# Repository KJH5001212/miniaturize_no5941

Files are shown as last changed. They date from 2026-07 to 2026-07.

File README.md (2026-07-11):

# Discrete Potentiostat (초소형 무선충전 크로노암페로메트리)

AD5941 없이 디스크리트 듀얼 앰프로 구성한 3전극 크로노암페로메트리 디바이스.
WE-RE 간 **+0.5 V 고정 바이어스**, nA~µA 전류 측정, BLE 스트리밍, Qi 무선충전.

## 확정 부품

| 블록 | 부품 | 역할 |
|---|---|---|
| AFE | **LPV802** (듀얼, 나노파워) | A: 컨트롤 앰프 (CE 구동, RE 센스) / B: TIA (WE 전류→전압) — 0.32 µA/ch, Ib 0.1 pA |
| 레퍼런스 | **REF35102QDBVR** (1.024 V) | WE 가상전위 + 바이어스 분압 원천 |
| MCU/BLE/ADC | **nRF52832-QFAA (칩다운)** | 내장 SAADC(차동, 12-bit+오버샘플링)로 측정, BLE 전송. 32 MHz 수정 + Johanson 매칭필터 + 칩안테나 |
| LDO | **MIC5205-3.3** | 3.3 V 단일 레일 |
| 무선충전 | **BQ51013BRHLR** | Qi 수신, 레귤레이티드 5 V 출력 (VQFN-20) |
| 충전기 | **MCP73832T-2ACI/OT** | 리튬 충전 20 mA (=1000/RPROG), 종지 ~1.5 mA, SOT-23-5 |
| 배터리 | **LIR2032** | 3.7 V / ~40 mAh 코인셀 |

## 신호 체인

```
Qi 코일 ─ BQ51013B(5V) ─ MCP73832(20mA) ─ LIR2032 ─ MIC5205 ─ 3.3V ─┬─ nRF52832
                                                                     └─(GPIO 스위치드)─ REF35102, LPV802

REF35102 1.024V ──────────────────────────── TIA(+in): WE 가상전위 = 1.024V
      └─ 분압(1.00M/1.00M, 1:1) → 0.512V ── 컨트롤앰프(+in): RE 목표

E_cell = WE − RE = 1.024 − 0.512 = +0.512 V (대략 0.5 V 고정, 요구사항 충족)

WE → LPV802-B (TIA, RF=1MΩ) → V_out = 1.024 + I×RF
V_out, 1.024V → nRF52832 SAADC 차동 입력 → I = ΔV / RF → BLE
```

## 폴더 구성

- `hardware/design.md` — 회로 상세 설계 + 계산 (바이어스, TIA, SAADC, 충전, 전원, 보호)
- `hardware/bom.md` — 전체 BOM (수동소자 포함)
- `hardware/kicad/` — 회로도 + 23.4×22 mm 6층 PCB (배선 완료) + 생성기 스크립트
- `firmware/` — **펌웨어 (SAADC 직접측정, 구현 완료)** — 프로토콜/파라미터는 `firmware/README.md`
- `firmware-plan.md` — 포팅 계획 원문 (구현 완료 — 이력 참고용)

## 기존 ad5941 프로젝트와의 관계

BLE 프로토콜(NUS + JSON), 무손실 버퍼링, 런 모드(연속/타이머/사이클), Android 앱은
**그대로 재사용**한다. 교체되는 것은 측정 엔진뿐: SPI+AD5941 → SAADC+디스크리트 AFE.

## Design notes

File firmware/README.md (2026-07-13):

# 디스크리트 포텐쇼스탯 펌웨어 (nRF52832 SAADC 직접측정)

WE-RE **+0.512 V 하드웨어 고정 바이어스**(REF35102 + 1:1 분압)를 걸고,
LPV802 TIA 출력을 **nRF52832 SAADC 가 직접 측정**하는 크로노암페로메트리 펌웨어.
AD5941 버전(`/firmware`)과 **BLE 프로토콜 동일** — 기존 안드로이드 앱이 무수정으로 동작하고,
측정 파라미터(rf/os/게인 등)를 앱에서 조절하는 확장 필드가 추가됐다.

## AD5941 버전과의 차이

| | AD5941 버전 (`/firmware`) | 이 펌웨어 |
|---|---|---|
| 측정 | AD5941 이 측정, nRF 는 SPI 수신 | **nRF SAADC 가 직접 측정** (SPI 없음) |
| 전위 | LPDAC 로 생성 (+0.5 V) | 하드웨어 고정 (+0.512 V, REF35102) |
| 레인지 | RTIA 저항 전환 (11단) | **SAADC 게인 전환 (3단)** — RF 는 고정 저항 |
| RF | 내부 RTIA | 외부 2 MΩ (R9 — 교체 가능) → **`rf` 런타임 설정, 기본값 2M** |
| 분해능 | RTIA 오토레인지 | HW 오버샘플링(`os`) + 게인 4 구간, ≤0.1 nA |
| 캘리브레이션 | 없음 | **zero(오프셋)/cal(스케일)** — NVM 저장 |
| 배터리 | 없음 | VBAT 감시, 3.3 V 경고 / 3.0 V System OFF |

## 구성

| 파일 | 역할 |
|---|---|
| `src/main.c` | 측정 스레드(페이싱·오토레인지·캘리브레이션) · BLE NUS · 배터리 정책 |
| `src/meas.c` | SAADC 엔진 (차동 AIN0−AIN1, 게인 3단, HW 오버샘플) + AFE 전원 + VBAT/충전/Qi |
| `src/store.c` | `rf`/`os`/캘리브레이션 NVM 영속화 (settings/NVS) |
| `src/databuf.c` | 무손실 링버퍼 + ACK 윈도우 (AD5941 버전 그대로) |
| `src/flog.c` | **플래시 오프라인 백로그** — 폰 없이 측정, 재연결 시 자동 동기화 (96KB, ~6,100샘플) |
| `src/cmd.c` | JSON 명령 파서 (rf/os/zero/cal 확장) |
| `app.overlay` | 보드 핀맵 · SAADC 활성 · LDO 모드(DCC 미접속 보드 기준) |
| `prj.conf` | BLE(NUS)/ADC/FPU/RTT/settings/LFRC 설정 |

## 측정 원리

- **바이어스**: 하드웨어 고정. AVDD 급전 GPIO(P0.26) HIGH → REF35102(1.024 V) + LPV802 급전(~2 µA),
  50 ms 안정화 후 샘플링. 정지 시 LOW → 소모 0 + CE 차단(전극 분극 방지).
  (회로도 요건: DVDD→AVDD 상시 연결(R7 등) 제거, AVDD 는 P0.26 이 단독 급전)
- **TIA**: `V_TIA = 1.024 V + I×RF`. SAADC **차동**(AIN0=TIA_OUT, AIN1=1.024 V)이라
  ΔV = I×RF 를 오프셋 없이 직접 획득.
- **게인 레인지** (RF=1 MΩ 기준): idx0 = gain4 (±150 nA, LSB 73 pA) /
  idx1 = gain1 (±0.6 µA) / idx2 = gain1/2 (−0.9~+2.1 µA).
  오토레인지: |ΔV| > 85 % FS → 게인 다운, < 18 % FS → 게인 업 (히스테리시스+settle 폐기).
- **분해능**: HW 오버샘플 `os`(기본 64×) + 출력주기 내 소프트 평균 → ≤0.1 nA (요구 1 nA 대비 10×).
- **전류 환산**: `I[nA] = (ΔV/rf_ohm)×1e9 × scale − off[gain]` — scale/off 는 캘리브레이션값(NVM).

## BLE 프로토콜 (NUS, JSON 라인)

### 명령 (앱 → 기기) — 기존 앱 호환

```json
{"cmd":"start","mode":"continuous|timed|cycle","rate":10,"dur":60,"on":5,"off":295,"cycles":0,"auto":1,"range":0}
{"cmd":"config", ...같은 필드... }        // 실행 없이 설정만
{"cmd":"stop"}  {"cmd":"status"}  {"cmd":"ack","seq":1234}
```

### 확장: 측정 파라미터 (config/start 에 추가 필드)

| 필드 | 의미 | 범위 | 비고 |
|---|---|---|---|
| `rf` | TIA RF [Ω] | 10 k~100 M | 보드에서 RF 교체 시 전송 → **NVM 저장** (리플래시 불필요) |
| `os` | HW 오버샘플 | 1~256 | 2^n 절사, NVM 저장. RF 클수록 낮춰도 됨 (1 M→64, 10 M→4) |
| `auto` | 오토레인지 | 0/1 | 0 이면 `range` 게인 고정 |
| `range` | 게인 인덱스 | 0~2 | 0=최고감도(±150 nA@1 M) … 2=풀레인지(±2.1 µA@1 M) |
| `agg` | **요약 모드** | 0/1 | 1=측정구간당 **∫I·dt 후반부 선형회귀 기울기 1샘플**만 저장/전송 (raw 폐기). CYCLE/TIMED 전용, 기본 0 |

### 확장: 캘리브레이션 (유휴 상태에서만)

```json
{"cmd":"zero"}              // 셀 오픈(전극 미연결) 상태에서 — 게인별 오프셋 측정+저장
{"cmd":"cal","kohm":1000}   // 기지저항 더미셀 연결 상태 — 기대 I=512mV/R 로 스케일 보정
```
응답: `{"cal":"zero","off":[...]}` / `{"cal":"scale","exp_nA":...,"meas_nA":...,"scale":...}`

**RF 교체 절차**: ① 새 RF/CF 납땜 ② `{"cmd":"config","rf":5100000,"os":16}` ③ `zero` + `cal`.

### 데이터 (기기 → 앱) — 기존 앱 호환

```json
{"d":[[seq,t_ms,current_nA,range], ...]}   // 무손실 스트림 (ack 로 해제)
{"st":"idle|run|rest","mode":0,"rate":10,"cyc":3,"range":1,"pend":0,"buf":12,"gap":0,
 "vbat":3720,"chg":1,"qi":1,"lb":0,"rf":1000000,"os":64,"fpend":0,"agg":0}   // 상태 (1초 주기) — vbat 이후가 확장 필드
```

`chg` = 실제 충전 중(MCP73832 STAT) · `qi` = 충전패드 위(Qi 5V 수신, AIN3 분압 >2 V).
둘을 조합하면 앱에서 3상태 구분: 패드 밖(`qi:0`) / 충전 중(`qi:1,chg:1`) / 완충(`qi:1,chg:0`).
`fpend` = 플래시 백로그(미동기화 샘플 수) — 0 이 되면 동기화 완료.

## 웨어러블 오프라인 측정 (플래시 백로그)

폰 없이 착용한 채 측정하고, 나중에 앱을 열면 자동으로 밀린 데이터가 동기화된다.

- **저장**: BLE 미연결 동안 샘플이 내부 플래시 파티션(96KB)에 적층 —
  **~6,100샘플** = cycle(5초 측정/5분) raw 기준 **~10시간**, 1 Hz 연속 기준 ~1.7시간.
- **요약 모드(`agg:1`) 권장**: 사이클당 1샘플이 되어 같은 96KB 로 **~21일**.
  기울기 값은 후반 2.5초(25샘플 회귀)의 평균 효과로 끝값 대비 노이즈 ~5× 감소.
- **동기화**: 재연결하면 백로그를 오래된 것부터 기존 `{"d":...}`+ack 스트림으로
  재생 → **앱 무수정**. 배치 단위 stop-and-wait 라 ack 유실 시 재전송(중복은 앱이
  seq 로 제거). 백로그가 다 빠진 뒤 라이브 스트림 재개 (시간순 보존).
- **측정 중엔 재생 일시정지**: 백로그 재생은 IDLE/사이클 휴지기에만 —
  코인셀 IR 전압새그(라디오 버스트+측정 부하 중첩)와 라디오→아날로그 노이즈
  침투를 피하기 위함. 사이클 모드는 휴지기가 대부분이라 동기화 시간 충분.
- **재부팅 생존**: 페이지 헤더 + 레코드 CRC 로 부팅 시 백로그 복원 (3.0 V
  System OFF 후 충전해서 켜도 데이터 유지).
- **가득 차면**: 가장 오래된 페이지부터 덮어쓰고 status `gap:1` 로 보고.
- 마모 수명: cycle duty 기준 페이지당 지우기 주기가 길어 (~10 h/링 순환) 연간 수천
  사이클 — 1만 회 한계 대비 여유 큼. 고속 연속(10 Hz+) 장기 로깅은 외부 SPI 플래시
  확장 권장 (회로도에 자리만 예약해두는 옵션 있음).

## 배터리 정책 (LIR2032 무보호 셀)

- 10분마다 VBAT(AIN2, 1M:1M 분압) 측정 (부팅 직후 1회 즉시 측정) → status 의 `vbat`[mV].
- **< 3.3 V**: `lb:1` 경고, 신규 start 거부 (실행중 측정은 계속).
- **< 3.0 V** (충전중 아닐 때): 측정 정지 → 버퍼 플러시(최대 10 s) → **System OFF**.
- `chg`: MCP73832 STAT (1=충전중). 충전 중 측정은 노이즈 증가 — 앱에서 경고 권장.

## 빌드 (NCS, AD5941 버전과 동일 환경)

```powershell
west build -b nrf52dk/nrf52832 <이 폴더> -d <이 폴더>\build --pristine
```

- 보드 타깃은 DK 지만 `app.overlay` 가 실보드 핀맵/전원으로 전부 재정의한다.
- 32.768 kHz 크리스탈 없음 → `CONFIG_CLOCK_CONTROL_NRF_K32SRC_RC=y` (이미 설정).
- DCC 미접속(인덕터 없음) → LDO 모드 (nRF 기본값 — overlay 에 `&reg` 오버라이드 없음).
  DC/DC 인덕터를 실장한 보드라면 `&reg { regulator-initial-mode = <NRF5X_REG_MODE_DCDC>; }` 추가.
- **flog 파티션**: 0x62000~0x7A000 (96KB). 빌드 로그의 FLASH 사용량이 **392KB(0x62000)를 넘으면** app.overlay 의 파티션 시작을 뒤로 밀 것.
- 플래시: J-Link + SWD (SWDIO/SWDCLK 테스트포인트 + 3V3/GND).

### 핀맵 (app.overlay 와 일치 — 다른 보드 리비전이면 overlay 만 수정)

| 기능 | 핀 | 비고 |
|---|---|---|
| TIA 출력 (차동 +) | P0.02/AIN0 | ΔV = I×RF |
| VREF 1.024 V (차동 −) | P0.03/AIN1 | REF35102 |
| VBAT 모니터 | P0.04/AIN2 | 1M:1M 분압 |
| Qi 패드 감지 (`qi`) | P0.05/AIN3 | MCP73832_VDD(≈5 V) 1M:1M 분압 |
| AVDD 급전 (AFE 전원) | P0.26 | high-drive 출력 — DVDD→AVDD 상시 연결 없어야 함 |
| 충전 상태 (`chg`) | P0.08 | MCP73832 STAT, 100k 풀업, LOW=충전중 |
| LED (옵션) | P0.06 | 미실장이어도 무해 |

## 검증 순서 (firmware-plan.md §검증)

1. RTT 로 부팅 확인 → `status` 로 vbat/rf/os 확인
2. 더미셀(1 MΩ) 연결 → `start` → 이론값 512 nA 부근 확인 → `cal` 로 보정
3. 셀 오픈 → `zero` → 오프셋(±3.5 nA@1 M, LPV802 Vos) 제거 확인
4. 기지저항 3점(100 k/1 M/10 M)으로 게인별 선형성·오토레인지 전환 확인
5. 충전 중 노이즈 플로어 측정 → "충전 중 측정 금지" 정책 확정

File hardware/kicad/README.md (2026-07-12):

# KiCad 회로도

`discrete-potentiostat.kicad_sch` — KiCad 7 포맷 (KiCad 7/8/9에서 열림), 심볼 전부 파일에 내장(라이브러리 설치 불필요).
`discrete-potentiostat.pdf` — 렌더링본.

## 검증 상태 (Rev A)

| 항목 | 상태 |
|---|---|
| 넷 연결 | ✅ **설계 넷리스트 38개 vs `kicad-cli` 추출 넷리스트 완전 일치** (`generator/check_nets.py`) |
| BQ51013BRHL 핀맵 | ✅ KiCad 공식 BQ51050BRHL 심볼(동일 계열 패키지) 기반 + 차이 핀(4 OUT, 10 EN1) 데이터시트 확인 |
| MCP73832 핀맵 | ✅ KiCad 공식 라이브러리 (1 STAT / 2 VSS / 3 VBAT / 4 VDD / 5 PROG) |
| MIC5205 핀맵 | ✅ KiCad 공식 라이브러리 (1 IN / 2 GND / 3 EN / 4 BYP / 5 OUT) |
| LPV802 DGK 핀맵 | ✅ 표준 듀얼 (1 OUTA / 2 −INA / 3 +INA / 4 V− / 5 +INB / 6 −INB / 7 OUTB / 8 V+) — VSSOP-8, OPA2391과 핀·풋프린트 호환 |
| REF35102 DBV 핀맵 | ✅ 데이터시트 확인 (1,2 GND / 3 EN / 4 VIN / 5 NR / 6 VREF) |
| nRF52832-QFAA 핀맵 (48+EP) | ✅ KiCad 공식 라이브러리 (MCU_Nordic:nRF52832-QFxx) |
| RF 프런트엔드 | ✅ Johanson 2450FM07A0029 = nRF52832 QFN 전용 매칭 LPF (벤더 확인) — 4핀 배치는 데이터시트 랜드패턴 따를 것 |
| DEC2/DEC3 미연결 | ✅ QFN48 레퍼런스 기준 (DEC2 확인됨) / ⚠️ DEC3는 최신 PS로 재확인 권장 |
| 충전전류 공식 | ✅ MCP73832: ICHG = 1000/RPROG = 20 mA · BQ51013B ILIM: RILIM = 250/IMAX |

**칩다운 전환(2026-07-10)**: MDBT42Q 모듈 → nRF52832-QFAA 베어칩. RF 체인은
ANT(30) → FL1(매칭 LPF) → R15(0R)/C34(DNP) 튜닝 슬롯 → 칩안테나. RF 레이아웃은 Nordic
QFN48 레퍼런스를 트레이스 형상까지 복사하고, 실보드에서 VNA로 안테나 튜닝할 것.

## 핀 할당 (nRF52832)

| 기능 | 핀 | QFN48 핀 번호 |
|---|---|---|
| SAADC 차동 N (VREF 1.024 V) | P0.02/AIN0 | 4 |
| SAADC 차동 P (TIA 출력) | P0.03/AIN1 | 5 |
| VBAT 모니터 | P0.04/AIN2 | 6 |
| AFE 전원 (high-drive) | P0.06 | 8 |
| 상태 LED | P0.07 | 9 |
| 충전 상태 (STAT, 100k 풀업) | P0.08 | 10 |
| RESET / SWD | P0.21(24) / SWDCLK(25) / SWDIO(26) | — |

## PCB (`discrete-potentiostat.kicad_pcb`) — RevC

**23.4×22 mm, 6층, 양면 실장** (2026-07-11 RevC — RevB 26×24 대비 면적 **-17.5%**).
크기 하한 근거: 폭 = 배터리 탭 패드(중심 ±9.8 + 패드 1.4 + 엣지 0.3 ≈ 23.0),
높이 = 셀 존 Ø21 + 여유. **이보다 더 줄이려면 배터리/탭 구조 자체를 바꿔야 함.**
IC 전부 윗면; 뒷면은 코너 포켓 4곳(R1·R2·TH1 좌상 / R3 우하 / R5·R6·C15 좌하)만 사용
— 뒷면 중앙 **Ø21 mm 원**(Cmts 표시)은 LIR2032 탭셀 전용. J2(SWD)·TP1-3은 앞면 우측 열로
이동(배터리와 충돌 방지 + 납땜 접근성), R4·R10/C21(DNP)은 앞면 여유 공간.
스택업: **L1 신호/RF · L2 GND · L3 배선 · L4 배선 · L5 GND · L6 신호+배터리 패드**.
설계규칙(보드에 저장): 트랙 최소 0.09 / 클리어런스 0.09 / 비아 0.4/0.2 — JLC 6층 표준 공정 내.

| 항목 | 상태 |
|---|---|
| 배치 | ✅ 겹침 0 · 보드이탈 0 · 배터리존 침범 0 (`check_pcb.py`) — J1/J2는 **Ø1.0 mm 원형 납땜 패드**(와이어 직납, 피치 1.8 mm) |
| GND | ✅ L2·L5 통짜 플레인 + F/B 포어 + 스티칭 비아, 고립 동박 0 |
| RF 급전 | ✅ ANT(U3.30)→FL1→pi 슬롯(C35/R15/C34)→칩안테나. **E1 은 데이터시트(36S0021A Rev4.1) 확정 4단자 랜드패턴** — 1·4 Feed(브리지 급전), 2·3 GND(좌측 포어로 0.3mm 스트립), 에지 수직 장착 |
| 신호 배선 | ✅ **전 넷 100% 배선 완료** (77넷, 미결선 0) — 자동배선 + 마지막 4링크(DCC/DEC1/ADC_P/CLAMP2)는 검증된 수동 경로(`close4.py`), 비아-인-패드 2곳(U3.47, C30) 포함 |
| DRC | ✅ `drc-report.txt`: **동박 위반 0** (미결선 0 · 클리어런스 0 · 홀 0 · 엣지 0 · 고립 0). 남은 항목은 실크 겹침/코트야드/서멀 릴리프 경고성 코스메틱 |

### 4층 축소 검토 결과 (2026-07-11)

**불가 판정.** 같은 배치(23.4×22 양면)에서 4층(배선층 3개: F/In2/B)으로 세 가지 전략
(프레시, 우선순위 선배선, AGGRO 립업)을 시도했으나 최소 12~22패드 미결선으로 수렴 실패.
U3 서쪽 핀 탈출과 U1 QFN 코너가 배선층 4개(6층)를 요구함. 4층을 원하면 보드를
~26×24 이상으로 키우고 단면 실장로 돌아가는 트레이드오프가 필요할 것으로 추정
(6층 유지 권장 — JLC 기준 6층 프로토 비용 차이는 수량 적을 때 크지 않음).

주의: 비아-인-패드 2곳(U3.47 DCC, C30.1 DEC1)과 U1.47 비아는 리플로우 시 솔더 위킹
가능성이 있음 — 프로토 수조립에서는 문제없고, 양산 시 via tenting/plugging 지정 권장.

### 남은 작업 (KiCad GUI에서 배선 불필요!)

1. 보드 열기 → `B`(존 채우기) → DRC 실행해 동박 위반 0 확인
2. 커스텀 풋프린트 랜드패턴 대조: **E1 완료**(36S0021A Rev4.1 반영) / FL1·코일 패드는 데이터시트 대조 남음
3. 실크 정리(선택) → File → Fabrication Outputs → Gerber 출력
4. 안테나는 실보드에서 VNA로 튜닝 (R15 0R ↔ C34/C35 DNP 슬롯)

## 재생성 방법

```bash
sudo apt install kicad kicad-symbols   # 공식 심볼 라이브러리 필요
cd generator
python3 extract_syms.py                # 시스템 라이브러리에서 베이스 심볼 추출
python3 gen_sch.py                     # ../discrete-potentiostat.kicad_sch 생성
kicad-cli sch export netlist --output out.net ../discrete-potentiostat.kicad_sch
python3 check_nets.py                  # 넷리스트 일치 확인 (RESULT: PASS 확인)
python3 gen_pcb.py                     # ../discrete-potentiostat.kicad_pcb 생성 (pcbnew API)
python3 check_pcb.py                   # 배치 겹침/보드이탈 검사 (flagged: 0 확인)
python3 route_pcb.py                   # 자동배선 (GND 스티칭 + A* 립업 라우터, 6층)
RESUME=1 python3 route_pcb.py          # 기존 배선 보존, 미결선만 이어서 배선
./route_loop.sh                        # DRC→미결선 목록→RESUME 수렴 루프 (×4)
# todo_override.json(DRC 미결선 목록)을 두면 RESUME이 그 목록만 공략
# PRIORITY=NET1,NET2 환경변수로 특정 넷을 최우선 배선 (막힌 코너 공략용)
```

배선이 특정 코너에서 계속 실패하면: 그 통로를 점거한 넷들의 트랙을 지우고
todo_override.json에 [실패넷들 우선, 걷어낸 넷들 나중] 순서로 넣은 뒤
`PRIORITY=... RESUME=1`로 재실행 (U1 QFN 코너가 이 방법으로 뚫렸음).
`gnd_fix.py`(GND 고아 패드/고립 섬 스티칭)와 `copper_fix.py`(RF 경로 검증 재배선,
좌표 하드코딩된 1회성 스크립트)는 기록용으로 남겨둠.

배치를 바꾸려면 `gen_pcb.py`의 `PLACE` 좌표를 수정하거나, KiCad GUI에서 직접 옮기면 된다
(회로 연결은 라벨 기반이라 심볼을 옮겨도 넷은 유지됨).

## 회로도에 박혀 있는 주의사항 (DESIGN NOTES 텍스트 블록)

1. 충전은 2단: BQ51013B(Qi→5V, ILIM 100 mA) + MCP73832(20 mA/4.2 V, 종지 1.5 mA) — BQ51050B 직접충전(TI <200 mA 비권장) 대체
2. 공진탱크는 L=47 µH 기준 — 코일 변경 시 C1/C2 재계산
3. 칩다운 RF: Nordic QFN48 레퍼런스 레이아웃 복사 + 실보드 안테나 튜닝(R15/C34 슬롯), DEC3 최신 PS 확인
4. WE 노드 가드링(VREF 구동), 플럭스 세정
5. R10/C21(보상망)은 DNP — CE-RE 루프 발진 시만 실장
6. LIR2032 무보호 — 3.0 V 미만 System OFF 펌웨어 필수

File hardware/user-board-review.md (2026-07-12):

# 사용자 회로도(수기 설계) 검토 기록 — 2026-07-12

`/discrete-potentiostat/firmware` 가 타깃하는 실제 보드는 사용자가 KiCad 로 직접 그린
회로도다 (이 저장소의 `hardware/kicad` RevC 와는 별개 설계 — 토폴로지는 동일).
이 문서는 그 회로도에 대한 리뷰 결론과 확정 파라미터의 기록이다.

## 확정 핀맵 (펌웨어 `app.overlay` 와 1:1)

| 기능 | 핀 | 비고 |
|---|---|---|
| TIA 출력 (SAADC 차동 +) | P0.02/AIN0 | |
| VREF 1.024 V (차동 −) | P0.03/AIN1 | REF35102 |
| VBAT 모니터 | P0.04/AIN2 | 1M:1M 분압 (`Vbat` 넷 = 스위치 앞) |
| Qi 패드 감지 (`qi`) | P0.05/AIN3 | MCP73832_VDD(≈5 V) 1M:1M 분압 |
| AVDD 급전 (AFE 전원) | **P0.26** (QFN 38) | high-drive. R7 삭제로 DVDD 와 완전 분리 |
| 충전 상태 (`chg`) | P0.08 | MCP73832 STAT, 100k→DVDD 풀업, LOW=충전중 |
| LED (옵션) | P0.06 | 기본 미실장 |

## 전원 토폴로지 (치명 오류 2회 수정 후 확정)

```
Qi 5V(BQ51013B OUT) ── MCP73832_VDD ── U7 VDD + C19/C27 + R15(Charge 분압)
U7 VBAT ── Vbat ── 배터리+ + C28 + 스위치 공통 + R13(VBAT 분압)   ← 충전: 스위치 무관
스위치 출력 ── 3V7 ── LDO IN/EN                                   ← 기기: 스위치 제어
AVDD ← P0.26 단독 급전 (측정 시에만 ON → 분극 방지)              ← AFE: 펌웨어 제어
```

수정 이력: ① 초판 — U7 VBAT 미연결(충전 불가) + 스위치 양단이 같은 넷(무효) +
Charge 가 ADC 없는 P0.06. ② 2판 — BQ OUT↔스위치출력 라벨 맞바뀜(5V 배터리 직결
위험) + R7 잔존. ③ 3판에서 전부 해소 확인.

## 확정 부품 값

| 항목 | 값 | 근거 |
|---|---|---|
| Qi 코일 | Würth **760308101214** (26 µH ±10 %, Ø19, DCR 0.52 Ω) | 사용자 선정 |
| C13 (직렬 공진) | **82 nF** C0G 50 V **1206** | Ls'(패드 위 +15 %) 기준 fs≈100 kHz. 68/100 nF 예비로 실측 튜닝 |
| C24 (병렬 공진) | **1 nF** C0G 50 V 0402 | fd≈1 MHz (fd 는 허용폭 넓음) |
| R5 (PROG) | **49.9 k** → 20 mA | LIR2032 40 mAh 의 0.5C (25 k=40 mA=1C 는 과함) |
| R6 / C31 (제어루프) | **1 M / 10 nF** (τ=10 ms) | 10 M/100 nF(τ=1 s)에서 CA 응답 개선 |
| R10 / C33 (TIA→ADC) | **1 k / 1 µF** (fc≈160 Hz) | 50 k(3 Hz)에서 과도응답 복원 |
| R9 (TIA RF) | 2 M ∥ C32 100 pF | 펌웨어 기본 `rf`=2 M 일치. 레인지 약 −0.5~+1.1 µA |

## 수동소자 사이즈/정격 규칙 (0402 통일 불가 항목)

AC1/AC2/RECT 에 닿는 캡은 출력 5 V 와 무관하게 공진 배율·부하급변으로 수십 V 를 본다.

| Ref | 사이즈 | 사양 | 이유 |
|---|---|---|---|
| C13 | **1206** | 82 nF C0G 50 V | 0402 에 C0G 50 V 없음. X7R 대체 시 공진 표류(충전 간헐) — 시제품도 불가 |
| C22 (RECT) | **0805** | 10 µF X5R 25 V | RECT 평시 5~7 V + 스파이크 15 V+. 0402(6.3 V)는 파손 위험 — 시제품도 불가 |
| C18, C20 (CLAMP) | 0603 | 470 nF X7R 25 V | 클램프 동작 시 AC 피크 직격 |
| C19, C27, C28 | 0603 | 10µ/4.7µ X5R **10 V** | DC 바이어스 감쇄 — 0402 는 실효 30~40 % (충전기 발진 위험) |
| C11 (DVDD) | 0603 | 4.7 µF X5R 6.3 V↑ | Nordic 요구 4.7 µF 실효 확보 |
| C17/C21/C25/C26 | 0402 유지 | 10n/15n **50 V** X7R | AC 소용량은 50 V 품 지정으로 해결 |
| 나머지 전부 | 0402 | — | 저항 전체 포함 (µA~mA 라 발열 무관) |

참고: MCP73832 요구 최소는 4.7 µF — 초기 47 µF 는 과사양이었음. C27/C28 = 4.7 µF 0603 10 V 로 확정.

## 앱 배터리 표시 가이드

- status `vbat`[mV] → 잔량 룩업: 4200=100 % / 4000≈85 / 3900≈70 / 3800≈55 / 3700≈35 /
  3600≈20 / 3450≈10 / 3300=경고(`lb:1`) / 3000=컷오프. 충전 중엔 % 대신 "충전중" 표시.
- 충전 완료 판정: **`qi:1 && chg:0`** (패드 위 + STAT 해제 = 종지전류 도달).
- 3상태: 패드 밖(`qi:0`) / 충전중(`qi:1,chg:1`) / 완충(`qi:1,chg:0`).

## 잔여 과제

- [ ] FL1(2450FM07A0029, **3단자** — 사용자 데이터시트 확인) 심볼 GND 핀번호(현재 4)와
      풋프린트 패드 번호 일치 확인
- [ ] 조립 완성 상태(배터리 장착, 충전패드 위)에서 AC1-AC2 공진 실측 → C13 확정 (82n 시작, 68/100n 예비)
- [ ] 양산판: TS/CTRL 10 k 고정 → NTC 10 k(B3380) 배터리 밀착 교체 (온도 보호)
- [ ] BQ/nRF/MCP73832 의 EP(노출 패드)는 GND + 서멀 비아 (BQ 가 최대 발열원)
- [ ] 안테나(AE1)는 사용자 요청으로 검토 제외 — 실물 확정 시 랜드패턴 데이터시트 대조

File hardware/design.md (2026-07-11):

# 회로 상세 설계

3.3 V 단일 전원, 3전극(CE/RE/WE), WE vs RE = **+0.5 V 고정**.

## 1. 전원 트리

```
Qi RX 코일 → BQ51013B ─ 5V(V5OUT) → MCP73832(20mA) ─ 4.2V ─ LIR2032
                                      │
                                      ├─ VBAT 분압(1M/1M) → SAADC AIN (배터리 모니터)
                                      │
                                      └→ MIC5205-3.3 → 3.3V ─┬─ nRF52832 (VDD)
                                                              └─ (AFE_PWR: nRF GPIO) → REF35102, LPV802
```

- **MIC5205-3.3**: LIR2032 만충 4.2 V > nRF52832 절대최대 3.6 V이므로 필수. 드롭아웃 ~165 mV라
  VBAT ≈ 3.47 V까지 3.3 V 유지, 그 아래로는 추종 — 어차피 3.3 V 부근에서 펌웨어 컷오프하므로 문제없음.
  EN은 VBAT에 풀업(항상 온), BYP에 470 pF(노이즈 저감).
- **AFE 전원을 nRF GPIO에서 급전**: REF35102(<1 µA) + LPV802(0.32 µA/ch) 합계 **~2 µA**라
  GPIO(고드라이브 설정)로 직접 급전 가능. 미측정 시 GPIO LOW →
  - AFE 소모 전류 0
  - CE 구동이 끊겨 대기 중 전극 분극 방지 (별도 스위치 불필요)
- 예상 전류 예산:

| 상태 | 소모 | LIR2032 40 mAh 기준 |
|---|---|---|
| 대기 (nRF sleep + LDO IQ ~80 µA) | ~85 µA | ~19일 |
| 측정+BLE 스트리밍 | ~2–3 mA 평균 | ~13–20시간 연속 |

  ※ 대기시간의 지배 요인은 MIC5205의 자체소모(IQ). 더 길게 필요하면 추후 TPS7A02(IQ 25 nA)로
  핀호환 아님 주의하며 교체 검토.

## 2. 바이어스 네트워크 (≈ +0.5 V 고정)

REF35102 = **1.024 V** 하나로 WE 전위와 RE 목표를 모두 만든다.
정확히 0.5 V일 필요는 없고 "대략 0.5 V에 고정"이면 되므로, 분압을 **1:1**로 단순화한다.

- **WE 가상전위**: REF 출력을 TIA(+in)에 직결 → WE는 1.024 V에 고정.
- **RE 목표 전위**: REF를 1:1 분압해 컨트롤 앰프(+in)에 인가.

```
분압:  R1 = R2 = 1.00 MΩ (동일값 페어) → V_RE = 1.024 / 2 = 0.512 V
E_cell = 1.024 − 0.512 = +0.512 V  (고정, 분압 소모 0.5 µA)
```

- 인가 전위는 정확히 **+0.512 V**로 알려져 있으므로(레퍼런스 정밀도 그대로) 데이터 해석 시 이 값을 사용.
- 저항 1%품이면 E 오차 ±5 mV, 0.1%품이면 ±0.5 mV — 요구사항상 1%면 충분.
- 분압 중점에 **100 nF** (노이즈 필터). LPV802 입력 바이어스가 0.1 pA라 1 MΩ급 고임피던스 분압도 오차 무시 가능.
- REF35102 출력에 데이터시트 권장 출력 커패시터(0.1 µF) 배치.

## 3. 포텐시오스탯 코어 (LPV802)

LPV802 채택(사용자 결정): 나노파워 320 nA/ch, Ib 0.1 pA, GBW 8 kHz, Vos ±3.5 mV(max).
- **오프셋 영향**: E_cell 오차 ±3.5 mV(무시 가능) + TIA 출력 오프셋 → RF=1 MΩ 기준 **±3.5 nA 고정 오프셋**.
  펌웨어의 제로 캘리브레이션(셀 오픈 오프셋 측정)으로 제거되고, 온도 드리프트는 ~µV/°C급 → pA/°C라 문제없음.
  캘리브레이션 없이 절대정확도가 필요하면 핀호환 **LPV812**(±0.3 mV)로 업그레이드.
- **GBW 8 kHz**: TIA 대역은 CF가 340 Hz로 제한하므로 여유. CA 스텝 직후 응답이 수 ms로 느려질 뿐(10 Hz 샘플링에 무영향).

```
                    ┌──────────── CE (상대전극)
        0.512V ───(+)A
   RE ─────────────(−)A            A = 컨트롤 앰프: RE를 0.512 V로 유지하도록 CE 구동
                    └─ [보상: C 1nF + R 1kΩ 직렬, out→(−) 병렬 풋프린트]

   WE ──────────────(−)B ──┬─ RF 1MΩ ─┬── TIA_OUT
        1.024V ────(+)B    └─ CF 470pF ┘
```

### 컨트롤 앰프 (A)
- 루프가 RE를 0.512 V로 유지 → WE(1.024 V) 대비 **+0.512 V** 인가.
- RE는 (−) 입력으로만 연결 — fA급 입력이라 기준전극에 전류가 흐르지 않음 (RE 안정성 핵심).
- 전기화학 셀은 용량성 부하라 발진 여지 있음 → **CE에 직렬 100 Ω** + 출력→(−)입력 간
  **1 nF + 1 kΩ 직렬 보상망 풋프린트** 확보 (실측 후 실장 여부 결정).

### TIA (B)
- `V_TIA_OUT = 1.024 V + I_WE × RF` (산화전류 시 상승, 환원전류 시 하강)

#### RF 결정: 1 MΩ + 오버샘플링 vs 10 MΩ (요구 분해능 1 nA)

|  | RF = 1 MΩ | RF = 10 MΩ |
|---|---|---|
| 1 nA당 신호 | 1 mV | 10 mV |
| 풀스케일 | −0.9 / **+2.1 µA** | −92 / **+210 nA** |
| LSB (게인 1/2, 12-bit) | 0.59 nA | 0.059 nA |
| 1 nA 달성 조건 | 오버샘플링 필요 (64×면 노이즈 ~0.1 nA) | 오버샘플링 없이도 여유 17× |

- SAADC 자체 잡음 ~1.5 LSB rms 기준: 1 MΩ·게인 1/2에서 raw ~0.9 nA rms → **64× 오버샘플링으로 ~0.1 nA**, 1 nA 요구 충족.
  (CA 출력 10 Hz × 64× = 640 sps — SAADC 최대 200 ksps 대비 전혀 부담 없음.)
- 게인 4 구간(|I| < 150 nA)에서는 LSB 73 pA라 오버샘플링 없이도 1 nA를 훨씬 상회.
- 저항 열잡음은 양쪽 다 무시 가능 (1 MΩ: 2.4 pA rms @340 Hz).

**결론: RF = 1 MΩ (0.1%) + 오버샘플링 채택.**
결정 근거는 측정 상한 — 기존 AD5941 버전이 µA대까지 요구했으므로 10 MΩ(상한 210 nA)은 범위가 부족하다.
1 nA 분해능은 두 방법 모두 충족하므로, 범위가 넓은 쪽을 선택.
단, 실제 센서의 최대 전류가 ~200 nA 이하로 확정되면 10 MΩ로 교체하는 것이 더 견고(신호 10배, 오버샘플링 의존 제거) —
**10 MΩ 교체 풋프린트 유지** (CF는 47 pF로 함께 교체).

- **CF = 470 pF** → BW ≈ 340 Hz (안정성 + 노이즈 대역 제한; CA 샘플레이트 ≤100 Hz에 충분)
- **레이아웃**: WE–(−)B–RF 노드는 최단 배선, 주변에 1.024 V 가드링, 리플로우 후 플럭스 세정 필수
  (기생 리크 1 nA를 만들려면 보드 오염 저항이 수백 MΩ이면 충분하므로).

## 4. 전류 측정 (nRF52832 SAADC)

- **차동 측정**: AIN+ = TIA_OUT, AIN− = 1.024 V 노드 → 오프셋 없이 ΔV = I×RF 직접 획득.
- 각 입력에 RC 필터 (1 kΩ + 10 nF), acquisition time 40 µs.
- 소프트웨어 레인징 (아날로그 스위치 없이 SAADC 게인만 전환):

| SAADC 게인 | ΔV 범위 | LSB (RF=1 MΩ) | 256× 오버샘플링 시 유효분해능 |
|---|---|---|---|
| 1/2 | ±1.2 V | 0.59 nA | ~0.1 nA |
| 1 | ±0.6 V | 0.29 nA | ~0.05 nA |
| 4 | ±0.15 V | 73 pA | ~15 pA |

- 기존 AD5941 오토레인지(TIA 저항 전환)를 **SAADC 게인 오토레인지**로 대체:
  |ΔV|가 범위의 85% 초과 → 게인 다운, 20% 미만 → 게인 업. 전송 포맷의 `range` 필드 재사용.
- **캘리브레이션**: 기지 저항 더미셀(예: 1.00 MΩ → 이론 0.512 µA)로 RF·게인 오차 1회 보정, NVM 저장.
- **배터리 모니터**: VBAT → 1 M/1 M 분압 → AIN. 3.3 V 미만 경고, **3.0 V 미만 System OFF**
  (LIR2032는 맨셀이라 과방전 보호가 펌웨어 몫 — 충전 측은 MCP73832가 4.2 V 정전압으로 보호).

## 5. 무선충전 (BQ51013B + MCP73832 + LIR2032, 2단 구성)

BQ51050B 직접충전은 TI 공식 답변상 200 mA 미만에서 전류·종지 정밀도가 나빠 코인셀에 부적합
→ **Qi 수신(5 V)과 충전을 분리**하는 TI 권장 구조로 변경했다.

- **BQ51013BRHLR** (Qi WPC v1.2 수신, VQFN-20): 레귤레이티드 **5 V(V5OUT)** 출력.
  - 핀 배치는 BQ51050B와 동일 계열 (4번 BAT→OUT, 10번 TERM→EN1만 다름 — 데이터시트 확인).
  - **EN1 = EN2 = GND** → 무선충전 활성 (<00> 모드).
  - **ILIM**: `RILIM = KILIM/IMAX, KILIM = 250 A·Ω` → R1 2.32k + RFOD 200 Ω = 2.52 kΩ
    → IMAX 100 mA (하드웨어 리밋 1.2× ≈ 120 mA). 충전기 부하 20 mA 대비 충분한 여유.
  - **TS/CTRL**: 10 kΩ NTC를 셀 홀더 옆 배치 → 셀 과열 시 무선전력 차단
    (고정 10 kΩ로 대체하면 온도감시 비활성 — 데이터시트가 허용하는 안전 스트랩).
- **MCP73832T-2ACI/OT** (SOT-23-5, 4.2 V, 오픈드레인 STAT): LIR2032 전용 충전기.
  - **충전전류**: `ICHG = 1000 V / RPROG` → RPROG 49.9 kΩ = **20 mA (0.5 C)** — 저전류에서도 정밀.
  - **종지전류**: ICHG의 ~7.5 % ≈ **1.5 mA** — 40 mAh 셀에 적절.
  - STAT(오픈드레인) → 100 k 풀업(3V3) → nRF P0.08 = 충전 상태 모니터.
  - TI 권장 조합은 BQ51003+BQ25100이지만 둘 다 0.4 mm 피치 WCSP라 수조립이 어려워,
    기능 동등 + 납땜 가능한 BQ51013B(VQFN-20) + MCP73832(SOT-23-5)를 선택.
    더 작은 보드가 필요하면 BQ51003(DSBGA-28) + BQ25100(DSBGA-6)으로 교체 가능 (동일 토폴로지).
- **수신 코일**: TDK **WR202010-18M8-ID — 20×20×1.0 mm, 11 µH ±5%, DCR 350 mΩ, ~$3.6**.
  검토한 후보 중 최저가(뷔르트 Ø19 ~$7, Ø26.3 ~$11)이면서 배터리(Ø20)와 같은 풋프린트.
  주의: 정사각형이라 대각선이 28.3 mm → 원형 퍽 외형이면 Ø29 필요.
  **~22×22 mm 사각(모서리 라운드) 외형**이 이론 하한 — 실제 보드는 자동배선 여유를 위해
  **26×24 mm**(RevB)를 거쳐 양면 실장 재배치로 **23.4×22 mm**(RevC)까지 축소.
  폭 하한은 배터리 탭 패드가 결정 — 더 줄이려면 셀/탭 구조 변경 필요.
  공진 캡: C1(직렬) = 1/(L·(2π·100 kHz)²) = 230 nF → **220 nF C0G** (fs≈102 kHz, Qi 허용범위 내),
  C2(병렬) → **2.2 nF C0G** (fd≈1.03 MHz). 코일을 바꾸면 C1/C2 재계산 필수.
  트레이드오프: 소형 코일이라 송신패드 정렬에 민감 — 충전 부하 0.13 W라 실용상 문제없음.
- FOD 저항, RECT/BOOT 캐패시터는 데이터시트 레퍼런스 회로 그대로.
- 코일·정류 노드는 AFE와 보드 반대편/최대 이격 — 충전 중 측정은 비권장 (110–205 kHz 스위칭 노이즈).

## 6. 요약 스펙 (예상)

| 항목 | 값 |
|---|---|
| 인가 전위 | +0.512 V 고정 (1% 저항 시 ±5 mV) |
| 전류 범위 | −0.9 ~ +2.1 µA (RF 1 MΩ) |
| 분해능 | ≤0.1 nA (게인 1/2 + 64× OS), 요구 1 nA 대비 10× 마진 |
| 입력 바이어스 오차 | ~0.1 pA (LPV802) |
| 측정 대역 | ~340 Hz (CF로 제한) |
| 연속 측정 | 13–20 h / 대기 ~19일 (LIR2032 40 mAh) |

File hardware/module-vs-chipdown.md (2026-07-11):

# MDBT42Q 모듈 vs nRF52832 칩다운 — 크기·양산비용 검토

## 최종 결정 (2026-07-10): **칩다운 채택**

사용자 결정 — 무선 인증(의도적 방사체)을 어차피 받을 계획이라 모듈의 인증 승계 이점이 무의미하고,
단가($2.7 vs $3.5+)와 실장 유연성에서 칩다운이 유리. 회로도는 nRF52832-QFAA +
32 MHz 수정 + Johanson 2450FM07A0029(nRF52 전용 매칭 LPF) + 2450AT18B0100001E 칩안테나로 갱신됨.
전제 조건: RF 인증 예산(KC/FCC/CE RED)과 안테나 튜닝(VNA) 리소스 확보. 아래는 결정 당시의 비교 분석 원문.

---

(참고) 원래 분석 결론: 프로토타입~연 1만 대까지는 모듈 유지가 정석 — 크기는 코일·배터리가 결정하고,
칩다운의 단가 절감은 인증·RF 개발비(NRE)를 1만 대 이상 팔아야 회수한다.

## 1. 최종 크기는 무엇이 결정하나

"표준 Qi 무선충전 + LIR2032" 조합을 유지하는 한, 바꿀 수 없는 두 부품이 크기를 못박는다:

| 부품 | 크기 | 비고 |
|---|---|---|
| Qi RX 코일 (TDK WR202010-18M8-ID) | **20×20×1.0 mm** | 저부하(0.13 W)라 소형 코일 가능 |
| LIR2032 + 홀더 | **Ø20 mm, 높이 ~4.5 mm** | 셀 규격 고정 |
| → 디바이스 외형 | **~22×22 mm 사각 퍽, 두께 ~10 mm** | 크기 하한 = 배터리(Ø20)·코일(20×20) — 최종 보드는 **23.4×22 mm** (RevC, 양면 실장) |

Ø23 mm 원형 PCB의 실장 면적은 한 면 ~415 mm², 양면 ~830 mm².

| MCU 구현 | 점유 면적 | PCB 양면 대비 |
|---|---|---|
| MDBT42Q 모듈 | 160 mm² (16×10) | **19 %** |
| nRF52832 칩다운 (QFN48 6×6 + 32 MHz 크리스탈 + 칩안테나 + **안테나 킵아웃 ~55 mm²** + RF 수동소자 ~12개) | ~110 mm² | 13 % |

**절감분은 ~50 mm² = PCB의 6 %.** 외형은 배터리(Ø20)가 정하므로 칩다운해도
디바이스는 작아지지 않는다 (Ø23 보드에 모듈 19 % 점유 — 배치 여유 충분). 높이도 모듈(2.2 mm) < 셀 홀더(~4.5 mm)라 무관.

## 2. 배치 계획 (Ø23 mm 원형 PCB 기준)

```
        [12시] MDBT42Q — 안테나가 보드 가장자리 밖을 향하게, 킵아웃 확보
   [9시] 전원부(BQ51013B·탱크 캡·MCP73832)     [3시] MIC5205 + 디커플링
        — 뒷면 코일 인출선과 최단 연결
   [6시] AFE (REF35102·OPA2391·RF/CF) + 전극 패드/커넥터
        — 코일·스위칭 노드에서 최대 이격, WE 노드 가드링
   뒷면: LIR2032 홀더(중앙), SWD 패드, VBAT 분압
   보드 아래: Qi 코일(20×20×1.0) 적층 → 총 두께 ~10 mm
```

빡빡하지 않다. 모듈을 써도 AFE를 노이즈원에서 충분히 떼어놓을 여유가 있다.

## 3. 양산 비용 비교 (1k 기준 개략)

| 항목 | MDBT42Q | 칩다운 |
|---|---|---|
| 부품 단가 | 모듈 ~$3.5 | nRF52832 ~$2.3 + 크리스탈/안테나/수동소자 ~$0.4 = **~$2.7** |
| PCB | 2층 가능 (RF 없음) | RF 임피던스 컨트롤 필요 → 4층/공차 관리 +$0.1~0.3 |
| **단가 차** | — | **개당 ~$0.8~1.0 절감** |
| RF 설계 NRE | 0 | 안테나 매칭·튜닝 (챔버/외주) $3k~8k |
| 무선 인증 | **모듈 인증 승계** (KC·FCC·CE 모듈러) → 완제품 간이시험 ~$1k~3k | **의도적 방사체 신규 인증** KC + FCC + CE ~$10k~20k |
| 설계 리스크 | 없음 (검증된 RF) | 첫 스핀에 안테나 성능 실패 리스크 → 리스핀 비용·일정 |

**손익분기 ≈ (NRE $13k~25k) ÷ (개당 $0.8~1.0) ≈ 1.5만~2.5만 대.**

## 4. 결론과 전환 기준

- **지금~파일럿 양산: MDBT42Q-512KV2 유지.** 크기 이득 0, 확실성·인증·일정 이득 큼.
- **칩다운 전환을 검토할 시점** (아래 중 하나면):
  1. 연 판매 계획이 **2만 대 이상**으로 잡힐 때
  2. 표준 Qi를 포기하고(코일 소형화/독자 충전) **디바이스 지름을 <20 mm로 줄이는 재설계**를 할 때
     — 이 경우 어차피 전체 리레이아웃이므로 그때 칩다운을 같이 하는 게 맞다
- 전환 시에도 이 회로도의 **AFE·충전·전원 블록은 그대로 재사용** — 바뀌는 건 U3 블록(모듈 → 칩+RF)뿐.
- 중간 단계 대안: 더 작은 모듈(ANNA-B112, 6.5×6.5 mm)로 교체하면 재인증 없이 실장 면적을
  1/4로 — 단, 이것도 최종 외형은 안 줄어들기는 마찬가지.

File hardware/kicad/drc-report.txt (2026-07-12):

** Drc report for /home/user/ad5941/discrete-potentiostat/hardware/kicad/discrete-potentiostat.kicad_pcb **
** Created on 2026-07-12 03:26:16 **

** Found 397 DRC violations **
[silk_overlap]: Silkscreen overlap
    Rule: board setup constraints silk; Severity: warning
    @(108.3700 mm, 101.8000 mm): Reference 'C8'
    @(107.8900 mm, 101.9406 mm): Line on F.Silkscreen
[silk_overlap]: Silkscreen overlap
    Rule: board setup constraints silk; Severity: warning
    @(106.0344 mm, 100.8900 mm): Line on F.Silkscreen
    @(106.9700 mm, 101.8000 mm): Reference 'C7'
[silk_overlap]: Silkscreen overlap
    Rule: board setup constraints silk; Severity: warning
    @(106.4400 mm, 106.4000 mm): Reference 'C6'
    @(107.2050 mm, 105.9500 mm): Reference 'C9'
[silk_overlap]: Silkscreen overlap
    Rule: board setup constraints silk; Severity: warning
    @(107.2050 mm, 105.9500 mm): Reference 'C9'
    @(106.4400 mm, 104.4000 mm): Reference 'C4'
[silk_overlap]: Silkscreen overlap
    Rule: board setup constraints silk; Severity: warning
    @(106.4400 mm, 104.4000 mm): Reference 'C4'
    @(105.5700 mm, 104.4000 mm): Reference 'C3'
[silk_overlap]: Silkscreen overlap
    Rule: board setup constraints silk; Severity: warning
    @(103.7000 mm, 103.5000 mm): Reference 'U1'
    @(101.9387 mm, 103.5100 mm): Line on F.Silkscreen
[silk_overlap]: Silkscreen overlap
    Rule: board setup constraints silk; Severity: warning
    @(104.8300 mm, 104.6400 mm): Line on F.Silkscreen
    @(105.5700 mm, 104.4000 mm): Reference 'C3'
[silk_overlap]: Silkscreen overlap
    Rule: board setup constraints silk; Severity: warning
    @(115.6000 mm, 104.7500 mm): Reference 'C33'
    @(117.7000 mm, 104.0000 mm): Value '2450FM07A0029' of FL1
[silk_overlap]: Silkscreen overlap
    Rule: board setup constraints silk; Severity: warning
    @(117.5750 mm, 104.9000 mm): Reference 'C35'
    @(117.7000 mm, 104.0000 mm): Reference 'FL1'
[silk_overlap]: Silkscreen overlap
    Rule: board setup constraints silk; Severity: warning
    @(117.5750 mm, 104.9000 mm): Reference 'C35'
    @(117.7000 mm, 104.0000 mm): Value '2450FM07A0029' of FL1
[silk_overlap]: Silkscreen overlap
    Rule: board setup constraints silk; Severity: warning
    @(120.0750 mm, 102.8300 mm): Reference 'R15'
    @(117.7000 mm, 104.0000 mm): Value '2450FM07A0029' of FL1
[silk_overlap]: Silkscreen overlap
    Rule: board setup constraints silk; Severity: warning
    @(120.0750 mm, 102.8300 mm): Reference 'R15'
    @(119.4000 mm, 100.9500 mm): Value '2450AT07A0100' of E1
[silk_overlap]: Silkscreen overlap
    Rule: board setup constraints silk; Severity: warning
    @(119.4000 mm, 100.9500 mm): Value '2450AT07A0100' of E1
    @(117.7000 mm, 104.0000 mm): Value '2450FM07A0029' of FL1
[silk_overlap]: Silkscreen overlap
    Rule: board setup constraints silk; Severity: warning
    @(119.4000 mm, 100.9500 mm): Value '2450AT07A0100' of E1
    @(117.7000 mm, 104.0000 mm): Reference 'FL1'
[silk_overlap]: Silkscreen overlap
    Rule: board setup constraints silk; Severity: warning
    @(119.4000 mm, 100.9500 mm): Value '2450AT07A0100' of E1
    @(119.9214 mm, 103.6200 mm): Line on F.Silkscreen
[silk_overlap]: Silkscreen overlap
    Rule: board setup constraints silk; Severity: warning
    @(119.4000 mm, 100.9500 mm): Value '2450AT07A0100' of E1
    @(120.2550 mm, 104.9000 mm): Reference 'C34'
[silk_overlap]: Silkscreen overlap
    Rule: board setup constraints silk; Severity: warning
    @(117.7000 mm, 104.0000 mm): Value '2450FM07A0029' of FL1
    @(117.7000 mm, 104.0000 mm): Reference 'FL1'
[silk_overlap]: Silkscreen overlap
    Rule: board setup constraints silk; Severity: warning
    @(119.0950 mm, 105.0078 mm): Line on F.Silkscreen
    @(119.4000 mm, 100.9500 mm): Value '2450AT07A0100' of E1
[silk_overlap]: Silkscreen overlap
    Rule: board setup constraints silk; Severity: warning
    @(120.2550 mm, 104.9000 mm): Reference 'C34'
    @(117.7000 mm, 104.0000 mm): Value '2450FM07A0029' of FL1
[silk_overlap]: Silkscreen overlap
    Rule: board setup constraints silk; Severity: warning
    @(117.7000 mm, 104.0000 mm): Reference 'FL1'
    @(120.0750 mm, 102.8300 mm): Reference 'R15'
[silk_overlap]: Silkscreen overlap
    Rule: board setup constraints silk; Severity: warning
    @(117.7000 mm, 104.0000 mm): Reference 'FL1'
    @(115.6000 mm, 104.7500 mm): Reference 'C33'
[silk_overlap]: Silkscreen overlap
    Rule: board setup constraints silk; Severity: warning
    @(119.9400 mm, 107.6000 mm): Reference 'C26'
    @(119.4000 mm, 100.9500 mm): Value '2450AT07A0100' of E1
[silk_overlap]: Silkscreen overlap
    Rule: board setup constraints silk; Severity: warning
    @(119.9214 mm, 103.6200 mm): Line on F.Silkscreen
    @(120.2550 mm, 104.9000 mm): Reference 'C34'
[silk_overlap]: Silkscreen overlap
    Rule: board setup constraints silk; Severity: warning
    @(119.9214 mm, 103.6200 mm): Line on F.Silkscreen
    @(117.7000 mm, 104.0000 mm): Value '2450FM07A0029' of FL1
[silk_overlap]: Silkscreen overlap
    Rule: board setup constraints silk; Severity: warning
    @(117.7000 mm, 104.0000 mm): Value '2450FM07A0029' of FL1
    @(119.9214 mm, 104.3800 mm): Line on F.Silkscreen
[silk_overlap]: Silkscreen overlap
    Rule: board setup constraints silk; Severity: warning
    @(119.9214 mm, 104.3800 mm): Line on F.Silkscreen
    @(119.4000 mm, 100.9500 mm): Value '2450AT07A0100' of E1
[silk_overlap]: Silkscreen overlap
    Rule: board setup constraints silk; Severity: warning
    @(111.7000 mm, 111.0000 mm): PCB Text 'discrete-potentiostat 23x22 RevC 6L' on F.Silkscreen
    @(109.2922 mm, 110.7750 mm): Line on F.Silkscreen
[silk_overlap]: Silkscreen overlap
    Rule: board setup constraints silk; Severity: warning
    @(111.7000 mm, 111.0000 mm): PCB Text 'discrete-potentiostat 23x22 RevC 6L' on F.Silkscreen
    @(110.5250 mm, 110.7400 mm): Reference 'C13'
[silk_overlap]: Silkscreen overlap
    Rule: board setup constraints silk; Severity: warning
    @(107.9700 mm, 115.1000 mm): Reference 'C18'
    @(109.2000 mm, 116.4300 mm): Reference 'R9'
[silk_overlap]: Silkscreen overlap
    Rule: board setup constraints silk; Severity: warning
    @(107.9700 mm, 115.1000 mm): Reference 'C18'
    @(107.1400 mm, 115.0000 mm): Reference 'C17'
[silk_overlap]: Silkscreen overlap
    Rule: board setup constraints silk; Severity: warning
    @(107.9700 mm, 115.1000 mm): Reference 'C18'
    @(107.9400 mm, 115.1078 mm): Line on F.Silkscreen
[silk_overlap]: Silkscreen overlap
    Rule: board setup constraints silk; Severity: warning
    @(107.9700 mm, 115.1000 mm): Reference 'C18'
    @(107.7600 mm, 115.1078 mm): Line on F.Silkscreen
[silk_overlap]: Silkscreen overlap
    Rule: board setup constraints silk; Severity: warning
    @(108.8900 mm, 115.2406 mm): Line on F.Silkscreen
    @(109.3400 mm, 115.0000 mm): Reference 'C19'
[silk_overlap]: Silkscreen overlap
    Rule: board setup constraints silk; Severity: warning
    @(109.9100 mm, 115.2406 mm): Line on F.Silkscreen
    @(109.3400 mm, 115.0000 mm): Reference 'C19'
[silk_overlap]: Silkscreen overlap
    Rule: board setup constraints silk; Severity: warning
    @(109.9100 mm, 115.2406 mm): Line on F.Silkscreen
    @(110.2300 mm, 115.0000 mm): Reference 'R7'
[silk_overlap]: Silkscreen overlap
    Rule: board setup constraints silk; Severity: warning
    @(107.9700 mm, 115.1000 mm): Reference 'C18'
    @(101.2000 mm, 114.0000 mm): Value 'WR202010-18M8-ID 11uH' of L1
[silk_overlap]: Silkscreen overlap
    Rule: board setup constraints silk; Severity: warning
    @(107.9700 mm, 115.1000 mm): Reference 'C18'
    @(107.5800 mm, 112.7000 mm): Reference 'C14'
[silk_overlap]: Silkscreen overlap
    Rule: board setup constraints silk; Severity: warning
    @(109.2922 mm, 110.7750 mm): Line on F.Silkscreen
    @(110.5250 mm, 110.7400 mm): Reference 'C13'
[silk_overlap]: Silkscreen overlap
    Rule: board setup constraints silk; Severity: warning
    @(109.4000 mm, 109.9750 mm): Reference 'C12'
    @(110.5250 mm, 110.7400 mm): Reference 'C13'
[silk_overlap]: Silkscreen overlap
    Rule: board setup constraints silk; Severity: warning
    @(119.4000 mm, 100.9500 mm): Value '2450AT07A0100' of E1
    @(119.4000 mm, 100.9500 mm): Reference 'E1'
[silk_overlap]: Silkscreen overlap
    Rule: board setup constraints silk; Severity: warning
    @(111.0800 mm, 103.8000 mm): Reference 'C32'
    @(111.0800 mm, 101.6000 mm): Reference 'C11'
[silk_overlap]: Silkscreen overlap
    Rule: board setup constraints silk; Severity: warning
    @(109.2900 mm, 101.9406 mm): Line on F.Silkscreen
    @(109.7700 mm, 101.7000 mm): Reference 'C10'
[silk_overlap]: Silkscreen overlap
    Rule: board setup constraints silk; Severity: warning
    @(109.7700 mm, 101.7000 mm): Reference 'C10'
    @(110.3100 mm, 101.9406 mm): Line on F.Silkscreen
[silk_overlap]: Silkscreen overlap
    Rule: board setup constraints silk; Severity: warning
    @(111.0800 mm, 103.8000 mm): Reference 'C32'
    @(117.7000 mm, 104.0000 mm): Value '2450FM07A0029' of FL1
[silk_overlap]: Silkscreen overlap
    Rule: board setup constraints silk; Severity: warning
    @(111.0800 mm, 103.8000 mm): Reference 'C32'
    @(110.5300 mm, 104.5078 mm): Line on F.Silkscreen
[silk_overlap]: Silkscreen overlap
    Rule: board setup constraints silk; Severity: warning
    @(111.0800 mm, 103.8000 mm): Reference 'C32'
    @(110.6950 mm, 104.7406 mm): Line on F.Silkscreen
[silk_overlap]: Silkscreen overlap
    Rule: board setup constraints silk; Severity: warning
    @(110.5300 mm, 104.5078 mm): Line on F.Silkscreen
    @(117.7000 mm, 104.0000 mm): Value '2450FM07A0029' of FL1
[silk_overlap]: Silkscreen overlap
    Rule: board setup constraints silk; Severity: warning
    @(110.6950 mm, 104.7406 mm): Line on F.Silkscreen
    @(117.7000 mm, 104.0000 mm): Value '2450FM07A0029' of FL1
[silk_overlap]: Silkscreen overlap
    Rule: board setup constraints silk; Severity: warning
    @(117.7000 mm, 104.0000 mm): Value '2450FM07A0029' of FL1
    @(109.7750 mm, 104.6000 mm): Reference 'C27'
[silk_overlap]: Silkscreen overlap
    Rule: board setup constraints silk; Severity: warning
    @(109.7750 mm, 104.6000 mm): Reference 'C27'
    @(109.0100 mm, 104.4000 mm): Reference 'C5'
[silk_overlap]: Silkscreen overlap
    Rule: board setup constraints silk; Severity: warning
    @(109.7750 mm, 104.6000 mm): Reference 'C27'
    @(109.6200 mm, 106.2113 mm): Line on F.Silkscreen
[silk_overlap]: Silkscreen overlap
    Rule: board setup constraints silk; Severity: warning
    @(109.8100 mm, 104.5078 mm): Line on F.Silkscreen
    @(109.7750 mm, 104.6000 mm): Reference 'C27'
[silk_overlap]: Silkscreen overlap
    Rule: board setup constraints silk; Severity: warning
    @(111.8800 mm, 103.9078 mm): Line on F.Silkscreen
    @(117.7000 mm, 104.0000 mm): Value '2450FM07A0029' of FL1
[silk_overlap]: Silkscreen overlap
    Rule: board setup constraints silk; Severity: warning
    @(112.6000 mm, 102.2500 mm): Line on F.Silkscreen
    @(117.7000 mm, 104.0000 mm): Value '2450FM07A0029' of FL1
[silk_overlap]: Silkscreen overlap
    Rule: board setup constraints silk; Severity: warning
    @(112.6000 mm, 102.2500 mm): Line on F.Silkscreen
    @(112.6000 mm, 103.9078 mm): Line on F.Silkscreen
[silk_overlap]: Silkscreen overlap
    Rule: board setup constraints silk; Severity: warning
    @(117.7000 mm, 104.0000 mm): Value '2450FM07A0029' of FL1
    @(112.6000 mm, 103.9078 mm): Line on F.Silkscreen
[silk_overlap]: Silkscreen overlap
    Rule: board setup constraints silk; Severity: warning
    @(110.6900 mm, 101.8406 mm): Line on F.Silkscreen
    @(111.0800 mm, 101.6000 mm): Reference 'C11'
[silk_overlap]: Silkscreen overlap
    Rule: board setup constraints silk; Severity: warning
    @(107.5800 mm, 112.7000 mm): Reference 'C14'
    @(111.7000 mm, 111.0000 mm): PCB Text 'discrete-potentiostat 23x22 RevC 6L' on F.Silkscreen
[silk_overlap]: Silkscreen overlap
    Rule: board setup constraints silk; Severity: warning
    @(101.2000 mm, 114.0000 mm): Value 'WR202010-18M8-ID 11uH' of L1
    @(106.2400 mm, 115.0000 mm): Reference 'C16'
[silk_overlap]: Silkscreen overlap
    Rule: board setup constraints silk; Severity: warning
    @(101.2000 mm, 114.0000 mm): Value 'WR202010-18M8-ID 11uH' of L1
    @(104.6000 mm, 114.0400 mm): Line on F.Silkscreen
[silk_overlap]: Silkscreen overlap
    Rule: board setup constraints silk; Severity: warning
    @(106.2400 mm, 115.0000 mm): Reference 'C16'
    @(107.1400 mm, 115.0000 mm): Reference 'C17'
[silk_overlap]: Silkscreen overlap
    Rule: board setup constraints silk; Severity: warning
    @(101.2000 mm, 114.0000 mm): Value 'WR202010-18M8-ID 11uH' of L1
    @(107.1400 mm, 115.0000 mm): Reference 'C17'
[silk_overlap]: Silkscreen overlap
    Rule: board setup constraints silk; Severity: warning
    @(101.2000 mm, 114.0000 mm): Value 'WR202010-18M8-ID 11uH' of L1
    @(107.5800 mm, 112.7000 mm): Reference 'C14'
[silk_overlap]: Silkscreen overlap
    Rule: board setup constraints silk; Severity: warning
    @(107.5800 mm, 112.7000 mm): Reference 'C14'
    @(107.1400 mm, 115.0000 mm): Reference 'C17'
[silk_overlap]: Silkscreen overlap
    Rule: board setup constraints silk; Severity: warning
    @(109.8000 mm, 117.3700 mm): Reference 'R11'
    @(109.2000 mm, 116.4300 mm): Reference 'R9'
[silk_overlap]: Silkscreen overlap
    Rule: board setup constraints silk; Severity: warning
    @(109.8000 mm, 117.3700 mm): Reference 'R11'
    @(110.8300 mm, 119.2000 mm): Reference 'R13'
[silk_overlap]: Silkscreen overlap
    Rule: board setup constraints silk; Severity: warning
    @(109.8000 mm, 117.3700 mm): Reference 'R11'
    @(110.8300 mm, 117.4000 mm): Reference 'R12'
[silk_overlap]: Silkscreen overlap
    Rule: board setup constraints silk; Severity: warning
    @(109.5627 mm, 118.2775 mm): Line on F.Silkscreen
    @(109.8000 mm, 118.5700 mm): Reference 'C22'
[silk_overlap]: Silkscreen overlap
    Rule: board setup constraints silk; Severity: warning
    @(109.8000 mm, 118.5700 mm): Reference 'C22'
    @(109.0464 mm, 117.9800 mm): Line on F.Silkscreen
[silk_overlap]: Silkscreen overlap
    Rule: board setup constraints silk; Severity: warning
    @(111.7400 mm, 117.4000 mm): Reference 'C23'
    @(110.8300 mm, 117.4000 mm): Reference 'R12'
[silk_overlap]: Silkscreen overlap
    Rule: board setup constraints silk; Severity: warning
    @(111.7400 mm, 117.4000 mm): Reference 'C23'
    @(110.8300 mm, 119.2000 mm): Reference 'R13'
[silk_overlap]: Silkscreen overlap
    Rule: board setup constraints silk; Severity: warning
    @(111.7400 mm, 117.4000 mm): Reference 'C23'
    @(111.7400 mm, 119.2000 mm): Reference 'C24'
[silk_overlap]: Silkscreen overlap
    Rule: board setup constraints silk; Severity: warning
    @(111.7400 mm, 117.4000 mm): Reference 'C23'
    @(109.8000 mm, 118.5700 mm): Reference 'C22'
[silk_overlap]: Silkscreen overlap
    Rule: board setup constraints silk; Severity: warning
    @(111.7400 mm, 119.2000 mm): Reference 'C24'
    @(110.8300 mm, 117.4000 mm): Reference 'R12'
[silk_overlap]: Silkscreen overlap
    Rule: board setup constraints silk; Severity: warning
    @(111.7400 mm, 119.2000 mm): Reference 'C24'
    @(109.8000 mm, 118.5700 mm): Reference 'C22'
[silk_overlap]: Silkscreen overlap
    Rule: board setup constraints silk; Severity: warning
    @(111.7400 mm, 119.2000 mm): Reference 'C24'
    @(110.8300 mm, 119.2000 mm): Reference 'R13'
[silk_overlap]: Silkscreen overlap
    Rule: board setup constraints silk; Severity: warning
    @(111.7400 mm, 117.4000 mm): Reference 'C23'
    @(111.6200 mm, 117.5536 mm): Line on F.Silkscreen
[silk_overlap]: Silkscreen overlap
    Rule: board setup constraints silk; Severity: warning
    @(111.7400 mm, 117.4000 mm): Reference 'C23'
    @(112.8050 mm, 116.4000 mm): Reference 'C25'
[silk_overlap]: Silkscreen overlap
    Rule: board setup constraints silk; Severity: warning
    @(112.0400 mm, 115.6500 mm): Reference 'C20'
    @(111.7400 mm, 117.4000 mm): Reference 'C23'
[silk_overlap]: Silkscreen overlap
    Rule: board setup constraints silk; Severity: warning
    @(112.5400 mm, 117.5078 mm): Line on F.Silkscreen
    @(112.8050 mm, 116.4000 mm): Reference 'C25'
[silk_overlap]: Silkscreen overlap
    Rule: board setup constraints silk; Severity: warning
    @(113.2600 mm, 117.5078 mm): Line on F.Silkscreen
    @(112.8050 mm, 116.4000 mm): Reference 'C25'
[silk_overlap]: Silkscreen overlap
    Rule: board setup constraints silk; Severity: warning
    @(107.1400 mm, 115.0000 mm): Reference 'C17'
    @(107.0400 mm, 115.1078 mm): Line on F.Silkscreen
[silk_overlap]: Silkscreen overlap
    Rule: board setup constraints silk; Severity: warning
    @(108.6600 mm, 115.1078 mm): Line on F.Silkscreen
    @(109.3400 mm, 115.0000 mm): Reference 'C19'
[silk_overlap]: Silkscreen overlap
    Rule: board setup constraints silk; Severity: warning
    @(110.2300 mm, 115.0000 mm): Reference 'R7'
    @(101.2000 mm, 114.0000 mm): Value 'WR202010-18M8-ID 11uH' of L1
[silk_overlap]: Silkscreen overlap
    Rule: board setup constraints silk; Severity: warning
    @(110.2300 mm, 115.0000 mm): Reference 'R7'
    @(109.3400 mm, 115.0000 mm): Reference 'C19'
[silk_overlap]: Silkscreen overlap
    Rule: board setup constraints silk; Severity: warning
    @(101.2000 mm, 114.0000 mm): Value 'WR202010-18M8-ID 11uH' of L1
    @(109.3400 mm, 115.0000 mm): Reference 'C19'
[silk_overlap]: Silkscreen overlap
    Rule: board setup constraints silk; Severity: warning
    @(101.2000 mm, 114.0000 mm): Value 'WR202010-18M8-ID 11uH' of L1
    @(111.0500 mm, 113.0600 mm): Reference 'L2'
[silk_overlap]: Silkscreen overlap
    Rule: board setup constraints silk; Severity: warning
    @(110.2300 mm, 115.0000 mm): Reference 'R7'
    @(111.1300 mm, 115.5900 mm): Reference 'R8'
[silk_overlap]: Silkscreen overlap
    Rule: board setup constraints silk; Severity: warning
    @(110.2300 mm, 115.0000 mm): Reference 'R7'
    @(109.2000 mm, 116.4300 mm): Reference 'R9'
[silk_overlap]: Silkscreen overlap
    Rule: board setup constraints silk; Severity: warning
    @(110.2300 mm, 115.0000 mm): Reference 'R7'
    @(110.1400 mm, 115.1078 mm): Line on F.Silkscreen
[silk_overlap]: Silkscreen overlap
    Rule: board setup constraints silk; Severity: warning
    @(111.0200 mm, 115.1536 mm): Line on F.Silkscreen
    @(111.1300 mm, 115.5900 mm): Reference 'R8'
[silk_overlap]: Silkscreen overlap
    Rule: board setup constraints silk; Severity: warning
    @(112.0400 mm, 115.6500 mm): Reference 'C20'
    @(111.1300 mm, 115.5900 mm): Reference 'R8'
[silk_overlap]: Silkscreen overlap
    Rule: board setup constraints silk; Severity: warning
    @(101.2000 mm, 114.0000 mm): Value 'WR202010-18M8-ID 11uH' of L1
    @(112.0400 mm, 115.6500 mm): Reference 'C20'
[silk_overlap]: Silkscreen overlap
    Rule: board setup constraints silk; Severity: warning
    @(111.7800 mm, 115.1536 mm): Line on F.Silkscreen
    @(112.0400 mm, 115.6500 mm): Reference 'C20'
[silk_overlap]: Silkscreen overlap
    Rule: board setup constraints silk; Severity: warning
    @(112.0400 mm, 115.6500 mm): Reference 'C20'
    @(111.9200 mm, 115.7436 mm): Line on F.Silkscreen
[silk_overlap]: Silkscreen overlap
    Rule: board setup constraints silk; Severity: warning
    @(101.2000 mm, 114.0000 mm): Value 'WR202010-18M8-ID 11uH' of L1
    @(113.1600 mm, 113.4596 mm): Line on F.Silkscreen
[silk_overlap]: Silkscreen overlap
    Rule: board setup constraints silk; Severity: warning
    @(112.0400 mm, 115.6500 mm): Reference 'C20'
    @(112.8050 mm, 116.4000 mm): Reference 'C25'
[silk_overlap]: Silkscreen overlap
    Rule: board setup constraints silk; Severity: warning
    @(111.7400 mm, 117.4000 mm): Reference 'C23'
    @(111.1300 mm, 115.5900 mm): Reference 'R8'
[silk_overlap]: Silkscreen overlap
    Rule: board setup constraints silk; Severity: warning
    @(112.8400 mm, 115.7578 mm): Line on F.Silkscreen
    @(112.8050 mm, 116.4000 mm): Reference 'C25'
[silk_overlap]: Silkscreen overlap
    Rule: board setup constraints silk; Severity: warning
    @(111.7400 mm, 119.2000 mm): Reference 'C24'
    @(111.6200 mm, 119.3536 mm): Line on F.Silkscreen
[silk_overlap]: Silkscreen overlap
    Rule: board setup constraints silk; Severity: warning
    @(113.2600 mm, 119.3078 mm): Line on F.Silkscreen
    @(113.4400 mm, 119.4000 mm): Reference 'C21'
[silk_overlap]: Silkscreen overlap
    Rule: board setup constraints silk; Severity: warning
    @(109.8000 mm, 117.3700 mm): Reference 'R11'
    @(109.0464 mm, 117.2200 mm): Line on F.Silkscreen
[silk_overlap]: Silkscreen overlap
    Rule: board setup constraints silk; Severity: warning
    @(109.3400 mm, 115.0000 mm): Reference 'C19'
    @(109.2000 mm, 116.4300 mm): Reference 'R9'
[silk_overlap]: Silkscreen overlap
    Rule: board setup constraints silk; Severity: warning
    @(101.2000 mm, 114.0000 mm): Reference 'L1'
    @(101.2000 mm, 114.0000 mm): Value 'WR202010-18M8-ID 11uH' of L1
[silk_overlap]: Silkscreen overlap
    Rule: board setup constraints silk; Severity: warning
    @(106.2400 mm, 115.0000 mm): Reference 'C16'
    @(105.0000 mm, 116.1000 mm): Reference 'U4'
[silk_overlap]: Silkscreen overlap
    Rule: board setup constraints silk; Severity: warning
    @(105.4000 mm, 121.0000 mm): Value 'ELECTRODES' of J1
    @(105.4000 mm, 121.0000 mm): Reference 'J1'
[silk_overlap]: Silkscreen overlap
    Rule: board setup constraints silk; Severity: warning
    @(105.4000 mm, 121.0000 mm): Value 'ELECTRODES' of J1
    @(106.5000 mm, 120.2200 mm): Line on F.Silkscreen
[silk_overlap]: Silkscreen overlap
    Rule: board setup constraints silk; Severity: warning
    @(105.4000 mm, 121.0000 mm): Reference 'J1'
    @(106.5000 mm, 120.2200 mm): Line on F.Silkscreen
[silk_overlap]: Silkscreen overlap
    Rule: board setup constraints silk; Severity: warning
    @(105.4000 mm, 121.0000 mm): Value 'ELECTRODES' of J1
    @(110.8300 mm, 119.2000 mm): Reference 'R13'
[silk_overlap]: Silkscreen overlap
    Rule: board setup constraints silk; Severity: warning
    @(101.2000 mm, 114.0000 mm): Value 'WR202010-18M8-ID 11uH' of L1
    @(-1.3000 mm, -1.5100 mm): Polygon on F.Silkscreen
[silk_overlap]: Silkscreen overlap
    Rule: board setup constraints silk; Severity: warning
    @(101.2000 mm, 114.0000 mm): Value 'WR202010-18M8-ID 11uH' of L1
    @(104.6000 mm, 113.2000 mm): Reference 'U5'
[silk_overlap]: Silkscreen overlap
    Rule: board setup constraints silk; Severity: warning
    @(101.2000 mm, 114.0000 mm): Value 'WR202010-18M8-ID 11uH' of L1
    @(104.6000 mm, 114.0400 mm): Line on F.Silkscreen
[silk_overlap]: Silkscreen overlap
    Rule: board setup constraints silk; Severity: warning
    @(111.7000 mm, 111.0000 mm): PCB Text 'discrete-potentiostat 23x22 RevC 6L' on F.Silkscreen
    @(111.4000 mm, 111.3000 mm): Reference 'U2'
[silk_overlap]: Silkscreen overlap
    Rule: board setup constraints silk; Severity: warning
    @(110.5250 mm, 110.7400 mm): Reference 'C13'
    @(111.4000 mm, 111.3000 mm): Reference 'U2'
[silk_overlap]: Silkscreen overlap
    Rule: board setup constraints silk; Severity: warning
    @(110.5250 mm, 110.7400 mm): Reference 'C13'
    @(111.4000 mm, 110.4600 mm): Line on F.Silkscreen
[silk_overlap]: Silkscreen overlap
    Rule: board setup constraints silk; Severity: warning
    @(109.4000 mm, 109.9750 mm): Reference 'C12'
    @(111.4000 mm, 110.4600 mm): Line on F.Silkscreen
[silk_overlap]: Silkscreen overlap
    Rule: board setup constraints silk; Severity: warning
    @(111.4000 mm, 111.3000 mm): Reference 'U2'
    @(110.3844 mm, 111.6600 mm): Line on F.Silkscreen
[silk_overlap]: Silkscreen overlap
    Rule: board setup constraints silk; Severity: warning
    @(111.7000 mm, 111.0000 mm): PCB Text 'discrete-potentiostat 23x22 RevC 6L' on F.Silkscreen
    @(112.5000 mm, 110.0000 mm): Reference 'U3'
[silk_overlap]: Silkscreen overlap
    Rule: board setup constraints silk; Severity: warning
    @(111.7000 mm, 111.0000 mm): PCB Text 'discrete-potentiostat 23x22 RevC 6L' on F.Silkscreen
    @(-1.3000 mm, -1.5100 mm): Polygon on F.Silkscreen
[silk_overlap]: Silkscreen overlap
    Rule: board setup constraints silk; Severity: warning
    @(112.5000 mm, 110.0000 mm): Reference 'U3'
    @(-1.3000 mm, -1.5100 mm): Polygon on F.Silkscreen
[silk_overlap]: Silkscreen overlap
    Rule: board setup constraints silk; Severity: warning
    @(111.4000 mm, 111.3000 mm): Reference 'U2'
    @(112.5000 mm, 110.0000 mm): Reference 'U3'
[silk_overlap]: Silkscreen overlap
    Rule: board setup constraints silk; Severity: warning
    @(110.5250 mm, 110.7400 mm): Reference 'C13'
    @(111.4000 mm, 110.4600 mm): Line on F.Silkscreen
[silk_overlap]: Silkscreen overlap
    Rule: board setup constraints silk; Severity: warning
    @(-3.1100 mm, -3.1100 mm): Polygon on F.Silkscreen
    @(114.2300 mm, 113.1500 mm): Reference 'L3'
[silk_overlap]: Silkscreen overlap
    Rule: board setup constraints silk; Severity: warning
    @(114.2300 mm, 113.1500 mm): Reference 'L3'
    @(113.6900 mm, 112.5600 mm): Line on F.Silkscreen
[silk_overlap]: Silkscreen overlap
    Rule: board setup constraints silk; Severity: warning
    @(101.2000 mm, 114.0000 mm): Value 'WR202010-18M8-ID 11uH' of L1
    @(114.2300 mm, 113.1500 mm): Reference 'L3'
[silk_overlap]: Silkscreen overlap
    Rule: board setup constraints silk; Severity: warning
    @(110.3844 mm, 112.6800 mm): Line on F.Silkscreen
    @(111.0500 mm, 113.0600 mm): Reference 'L2'
[silk_overlap]: Silkscreen overlap
    Rule: board setup constraints silk; Severity: warning
    @(112.6000 mm, 105.5500 mm): Line on F.Silkscreen
    @(115.4922 mm, 105.5500 mm): Line on F.Silkscreen
[silk_overlap]: Silkscreen overlap
    Rule: board setup constraints silk; Severity: warning
    @(119.9400 mm, 109.4000 mm): Reference 'C28'
    @(119.9400 mm, 107.6000 mm): Reference 'C26'
[silk_overlap]: Silkscreen overlap
    Rule: board setup constraints silk; Severity: warning
    @(119.9400 mm, 109.4000 mm): Reference 'C28'
    @(119.4000 mm, 100.9500 mm): Value '2450AT07A0100' of E1
[silk_overlap]: Silkscreen overlap
    Rule: board setup constraints silk; Severity: warning
    @(119.9400 mm, 107.6000 mm): Reference 'C26'
    @(119.9100 mm, 107.4400 mm): Line on F.Silkscreen
[silk_overlap]: Silkscreen overlap
    Rule: board setup constraints silk; Severity: warning
    @(119.9400 mm, 107.6000 mm): Reference 'C26'
    @(119.9100 mm, 106.8900 mm): Line on F.Silkscreen
[silk_overlap]: Silkscreen overlap
    Rule: board setup constraints silk; Severity: warning
    @(119.9100 mm, 106.8900 mm): Line on F.Silkscreen
    @(119.4000 mm, 100.9500 mm): Value '2450AT07A0100' of E1
[silk_overlap]: Silkscreen overlap
    Rule: board setup constraints silk; Severity: warning
    @(112.8050 mm, 116.4000 mm): Reference 'C25'
    @(112.3800 mm, 117.5536 mm): Line on F.Silkscreen
[silk_overlap]: Silkscreen overlap
    Rule: board setup constraints silk; Severity: warning
    @(114.1100 mm, 117.2000 mm): Reference 'R10'
    @(113.7250 mm, 116.5406 mm): Line on F.Silkscreen
[silk_overlap]: Silkscreen overlap
    Rule: board setup constraints silk; Severity: warning
    @(114.1100 mm, 117.2000 mm): Reference 'R10'
    @(113.4400 mm, 119.4000 mm): Reference 'C21'
[silk_overlap]: Silkscreen overlap
    Rule: board setup constraints silk; Severity: warning
    @(110.8300 mm, 117.4000 mm): Reference 'R12'
    @(110.8300 mm, 119.2000 mm): Reference 'R13'
[silk_overlap]: Silkscreen overlap
    Rule: board setup constraints silk; Severity: warning
    @(110.8300 mm, 117.4000 mm): Reference 'R12'
    @(109.8000 mm, 118.5700 mm): Reference 'C22'
[silk_overlap]: Silkscreen overlap
    Rule: board setup constraints silk; Severity: warning
    @(109.8000 mm, 118.5700 mm): Reference 'C22'
    @(110.8300 mm, 119.2000 mm): Reference 'R13'
[silk_overlap]: Silkscreen overlap
    Rule: board setup constraints silk; Severity: warning
    @(111.7000 mm, 111.0000 mm): PCB Text 'discrete-potentiostat 23x22 RevC 6L' on F.Silkscreen
    @(119.9400 mm, 111.2000 mm): Reference 'C29'
[silk_overlap]: Silkscreen overlap
    Rule: board setup constraints silk; Severity: warning
    @(111.7000 mm, 111.0000 mm): PCB Text 'discrete-potentiostat 23x22 RevC 6L' on F.Silkscreen
    @(119.9400 mm, 109.4000 mm): Reference 'C28'
[silk_overlap]: Silkscreen overlap
    Rule: board setup constraints silk; Severity: warning
    @(119.9400 mm, 109.4000 mm): Reference 'C28'
    @(119.9400 mm, 111.2000 mm): Reference 'C29'
[silk_overlap]: Silkscreen overlap
    Rule: board setup constraints silk; Severity: warning
    @(111.7000 mm, 111.0000 mm): PCB Text 'discrete-potentiostat 23x22 RevC 6L' on F.Silkscreen
    @(120.7400 mm, 111.3078 mm): Line on F.Silkscreen
[silk_overlap]: Silkscreen overlap
    Rule: board setup constraints silk; Severity: warning
    @(119.9100 mm, 112.5600 mm): Line on F.Silkscreen
    @(119.9400 mm, 111.2000 mm): Reference 'C29'
[silk_overlap]: Silkscreen overlap
    Rule: board setup constraints silk; Severity: warning
    @(122.4000 mm, 110.6000 mm): Reference 'J2'
    @(122.4000 mm, 110.6000 mm): Value 'SWD' of J2
[silk_overlap]: Silkscreen overlap
    Rule: board setup constraints silk; Severity: warning
    @(111.7000 mm, 111.0000 mm): PCB Text 'discrete-potentiostat 23x22 RevC 6L' on F.Silkscreen
    @(121.4600 mm, 111.3078 mm): Line on F.Silkscreen
[silk_overlap]: Silkscreen overlap
    Rule: board setup constraints silk; Severity: warning
    @(117.3200 mm, 116.3000 mm): Reference 'C30'
    @(117.0000 mm, 118.0000 mm): Reference 'U6'
[silk_overlap]: Silkscreen overlap
    Rule: board setup constraints silk; Severity: warning
    @(117.3200 mm, 116.3000 mm): Reference 'C30'
    @(116.6700 mm, 116.4078 mm): Line on F.Silkscreen
[silk_overlap]: Silkscreen overlap
    Rule: board setup constraints silk; Severity: warning
    @(115.8700 mm, 116.3000 mm): Reference 'C31'
    @(117.0000 mm, 118.0000 mm): Reference 'U6'
[silk_overlap]: Silkscreen overlap
    Rule: board setup constraints silk; Severity: warning
    @(115.8700 mm, 116.3000 mm): Reference 'C31'
    @(115.8000 mm, 116.1922 mm): Line on F.Silkscreen
[silk_overlap]: Silkscreen overlap
    Rule: board setup constraints silk; Severity: warning
    @(122.3000 mm, 116.1520 mm): Reference 'TP2'
    @(122.3000 mm, 116.0000 mm): Circle on F.Silkscreen
[silk_overlap]: Silkscreen overlap
    Rule: board setup constraints silk; Severity: warning
    @(122.3000 mm, 116.0000 mm): Circle on F.Silkscreen
    @(122.3000 mm, 117.8000 mm): Circle on F.Silkscreen
[silk_overlap]: Silkscreen overlap
    Rule: board setup constraints silk; Severity: warning
    @(122.3000 mm, 117.8000 mm): Circle on F.Silkscreen
    @(122.3000 mm, 117.9520 mm): Reference 'TP3'
[silk_overlap]: Silkscreen overlap
    Rule: board setup constraints silk; Severity: warning
    @(122.3000 mm, 117.8000 mm): Circle on F.Silkscreen
    @(122.3000 mm, 119.6000 mm): Circle on F.Silkscreen
[silk_overlap]: Silkscreen overlap
    Rule: board setup constraints silk; Severity: warning
    @(122.3000 mm, 117.8000 mm): Circle on F.Silkscreen
    @(120.5200 mm, 118.8600 mm): Reference 'R14'
[silk_overlap]: Silkscreen overlap
    Rule: board setup constraints silk; Severity: warning
    @(122.3000 mm, 117.9520 mm): Reference 'TP3'
    @(120.5200 mm, 118.8600 mm): Reference 'R14'
[silk_overlap]: Silkscreen overlap
    Rule: board setup constraints silk; Severity: warning
    @(122.3000 mm, 119.6000 mm): Circle on F.Silkscreen
    @(120.5200 mm, 118.8600 mm): Reference 'R14'
[silk_overlap]: Silkscreen overlap
    Rule: board setup constraints silk; Severity: warning
    @(119.3464 mm, 118.8800 mm): Line on F.Silkscreen
    @(120.5200 mm, 118.8600 mm): Reference 'R14'
[silk_overlap]: Silkscreen overlap
    Rule: board setup constraints silk; Severity: warning
    @(120.5200 mm, 118.8600 mm): Reference 'R14'
    @(120.2750 mm, 119.6450 mm): Reference 'D1'
[silk_overlap]: Silkscreen overlap
    Rule: board setup constraints silk; Severity: warning
    @(120.3664 mm, 119.6500 mm): Line on F.Silkscreen
    @(120.2750 mm, 119.6450 mm): Reference 'D1'
[silk_overlap]: Silkscreen overlap
    Rule: board setup constraints silk; Severity: warning
    @(120.3664 mm, 120.4100 mm): Line on F.Silkscreen
    @(121.0750 mm, 120.3400 mm): Line on F.Silkscreen
[silk_overlap]: Silkscreen overlap
    Rule: board setup constraints silk; Severity: warning
    @(112.8050 mm, 116.4000 mm): Reference 'C25'
    @(112.6800 mm, 115.7436 mm): Line on F.Silkscreen
[silk_overlap]: Silkscreen overlap
    Rule: board setup constraints silk; Severity: warning
    @(111.1300 mm, 115.5900 mm): Reference 'R8'
    @(110.8600 mm, 115.1078 mm): Line on F.Silkscreen
[silk_overlap]: Silkscreen overlap
    Rule: board setup constraints silk; Severity: warning
    @(110.8300 mm, 117.4000 mm): Reference 'R12'
    @(111.1300 mm, 115.5900 mm): Reference 'R8'
[silk_overlap]: Silkscreen overlap
    Rule: board setup constraints silk; Severity: warning
    @(103.0300 mm, 120.7700 mm): Reference 'R5'
    @(103.9200 mm, 120.9000 mm): Reference 'R6'
[silk_overlap]: Silkscreen overlap
    Rule: board setup constraints silk; Severity: warning
    @(102.3700 mm, 121.0536 mm): Line on B.Silkscreen
    @(103.0300 mm, 120.7700 mm): Reference 'R5'
[silk_overlap]: Silkscreen overlap
    Rule: board setup constraints silk; Severity: warning
    @(103.0300 mm, 120.7700 mm): Reference 'R5'
    @(103.3400 mm, 121.0078 mm): Line on B.Silkscreen
[silk_overlap]: Silkscreen overlap
    Rule: board setup constraints silk; Severity: warning
    @(104.8600 mm, 120.9000 mm): Reference 'C15'
    @(103.9200 mm, 120.9000 mm): Reference 'R6'
[silk_overlap]: Silkscreen overlap
    Rule: board setup constraints silk; Severity: warning
    @(111.7000 mm, 111.2500 mm): Reference 'BT1'
    @(111.7000 mm, 111.2500 mm): Value 'LIR2032' of BT1
[silk_overlap]: Silkscreen overlap
    Rule: board setup constraints silk; Severity: warning
    @(104.0600 mm, 121.0078 mm): Line on B.Silkscreen
    @(103.9200 mm, 120.9000 mm): Reference 'R6'
[silk_overlap]: Silkscreen overlap
    Rule: board setup constraints silk; Severity: warning
    @(104.3700 mm, 101.5000 mm): Reference 'R2'
    @(103.3700 mm, 101.5000 mm): Reference 'R1'
[silk_overlap]: Silkscreen overlap
    Rule: board setup constraints silk; Severity: warning
    @(104.3700 mm, 101.5000 mm): Reference 'R2'
    @(103.8200 mm, 101.6536 mm): Line on B.Silkscreen
[silk_overlap]: Silkscreen overlap
    Rule: board setup constraints silk; Severity: warning
    @(103.3700 mm, 101.5000 mm): Reference 'R1'
    @(103.8200 mm, 101.6536 mm): Line on B.Silkscreen
[silk_overlap]: Silkscreen overlap
    Rule: board setup constraints silk; Severity: warning
    @(104.3700 mm, 101.5000 mm): Reference 'R2'
    @(105.3700 mm, 101.5000 mm): Reference 'TH1'
[silk_overlap]: Silkscreen overlap
    Rule: board setup constraints silk; Severity: warning
    @(103.3700 mm, 101.5000 mm): Reference 'R1'
    @(102.8200 mm, 101.6536 mm): Line on B.Silkscreen
[silk_over_copper]: Silkscreen clipped by solder mask
    Local override; Severity: warning
    @(111.7000 mm, 111.0000 mm): PCB Text 'discrete-potentiostat 23x22 RevC 6L' on F.Silkscreen
[silk_over_copper]: Silkscreen clipped by solder mask
    Local override; Severity: warning
    @(109.8000 mm, 117.3700 mm): Reference 'R11'
[silk_over_copper]: Silkscreen clipped by solder mask
    Local override; Severity: warning
    @(115.6000 mm, 104.7500 mm): Reference 'C33'
[silk_over_copper]: Silkscreen clipped by solder mask
    Local override; Severity: warning
    @(108.3700 mm, 101.8000 mm): Reference 'C8'
[silk_over_copper]: Silkscreen clipped by solder mask
    Local override; Severity: warning
    @(119.9400 mm, 109.4000 mm): Reference 'C28'
[silk_over_copper]: Silkscreen clipped by solder mask
    Local override; Severity: warning
    @(111.7400 mm, 117.4000 mm): Reference 'C23'
[silk_over_copper]: Silkscreen clipped by solder mask
    Local override; Severity: warning
    @(117.3200 mm, 116.3000 mm): Reference 'C30'
[silk_over_copper]: Silkscreen clipped by solder mask
    Local override; Severity: warning
    @(107.1400 mm, 115.0000 mm): Reference 'C17'
[silk_over_copper]: Silkscreen clipped by solder mask
    Local override; Severity: warning
    @(111.0800 mm, 103.8000 mm): Reference 'C32'
[silk_over_copper]: Silkscreen clipped by solder mask
    Local override; Severity: warning
    @(110.2300 mm, 115.0000 mm): Reference 'R7'
[silk_over_copper]: Silkscreen clipped by solder mask
    Local override; Severity: warning
    @(119.9400 mm, 107.6000 mm): Reference 'C26'
[silk_over_copper]: Silkscreen clipped by solder mask
    Local override; Severity: warning
    @(112.0400 mm, 115.6500 mm): Reference 'C20'
[silk_over_copper]: Silkscreen clipped by solder mask
    Local override; Severity: warning
    @(114.1100 mm, 117.2000 mm): Reference 'R10'
[silk_over_copper]: Silkscreen clipped by solder mask
    Local override; Severity: warning
    @(112.8050 mm, 116.4000 mm): Reference 'C25'
[silk_over_copper]: Silkscreen clipped by solder mask
    Local override; Severity: warning
    @(112.5000 mm, 110.0000 mm): Reference 'U3'
[silk_over_copper]: Silkscreen clipped by solder mask
    Local override; Severity: warning
    @(117.5750 mm, 104.9000 mm): Reference 'C35'
[silk_over_copper]: Silkscreen clipped by solder mask
    Local override; Severity: warning
    @(109.7700 mm, 101.7000 mm): Reference 'C10'
[silk_over_copper]: Silkscreen clipped by solder mask
    Local override; Severity: warning
    @(101.2000 mm, 114.0000 mm): Value 'WR202010-18M8-ID 11uH' of L1
[silk_over_copper]: Silkscreen clipped by solder mask
    Local override; Severity: warning
    @(106.2400 mm, 115.0000 mm): Reference 'C16'
[silk_over_copper]: Silkscreen clipped by solder mask
    Local override; Severity: warning
    @(115.8700 mm, 116.3000 mm): Reference 'C31'
[silk_over_copper]: Silkscreen clipped by solder mask
    Local override; Severity: warning
    @(114.2300 mm, 113.1500 mm): Reference 'L3'
[silk_over_copper]: Silkscreen clipped by solder mask
    Local override; Severity: warning
    @(105.4000 mm, 121.0000 mm): Reference 'J1'
[silk_over_copper]: Silkscreen clipped by solder mask
    Local override; Severity: warning
    @(105.4000 mm, 121.0000 mm): Value 'ELECTRODES' of J1
[silk_over_copper]: Silkscreen clipped by solder mask
    Local override; Severity: warning
    @(107.9700 mm, 115.1000 mm): Reference 'C18'
[silk_over_copper]: Silkscreen clipped by solder mask
    Local override; Severity: warning
    @(109.0100 mm, 104.4000 mm): Reference 'C5'
[silk_over_copper]: Silkscreen clipped by solder mask
    Local override; Severity: warning
    @(106.4400 mm, 104.4000 mm): Reference 'C4'
[silk_over_copper]: Silkscreen clipped by solder mask
    Local override; Severity: warning
    @(109.7750 mm, 104.6000 mm): Reference 'C27'
[silk_over_copper]: Silkscreen clipped by solder mask
    Local override; Severity: warning
    @(112.6000 mm, 102.2500 mm): Line on F.Silkscreen
[silk_over_copper]: Silkscreen clipped by solder mask
    Local override; Severity: warning
    @(112.6000 mm, 105.5500 mm): Line on F.Silkscreen
[silk_over_copper]: Silkscreen clipped by solder mask
    Local override; Severity: warning
    @(122.3000 mm, 116.1520 mm): Reference 'TP2'
[silk_over_copper]: Silkscreen clipped by solder mask
    Local override; Severity: warning
    @(119.9400 mm, 111.2000 mm): Reference 'C29'
[silk_over_copper]: Silkscreen clipped by solder mask
    Local override; Severity: warning
    @(107.2050 mm, 105.9500 mm): Reference 'C9'
[silk_over_copper]: Silkscreen clipped by solder mask
    Local override; Severity: warning
    @(111.7400 mm, 119.2000 mm): Reference 'C24'
[silk_over_copper]: Silkscreen clipped by solder mask
    Local override; Severity: warning
    @(120.2550 mm, 104.9000 mm): Reference 'C34'
[silk_over_copper]: Silkscreen clipped by solder mask
    Local override; Severity: warning
    @(113.4400 mm, 119.4000 mm): Reference 'C21'
[silk_over_copper]: Silkscreen clipped by solder mask
    Local override; Severity: warning
    @(109.4000 mm, 109.9750 mm): Reference 'C12'
[silk_over_copper]: Silkscreen clipped by solder mask
    Local override; Severity: warning
    @(111.1300 mm, 115.5900 mm): Reference 'R8'
[silk_over_copper]: Silkscreen clipped by solder mask
    Local override; Severity: warning
    @(119.4000 mm, 100.9500 mm): Reference 'E1'
[silk_over_copper]: Silkscreen clipped by solder mask
    Local override; Severity: warning
    @(119.4000 mm, 100.9500 mm): Value '2450AT07A0100' of E1
[silk_over_copper]: Silkscreen clipped by solder mask
    Local override; Severity: warning
    @(117.7000 mm, 104.0000 mm): Reference 'FL1'
[silk_over_copper]: Silkscreen clipped by solder mask
    Local override; Severity: warning
    @(117.7000 mm, 104.0000 mm): Value '2450FM07A0029' of FL1
[silk_over_copper]: Silkscreen clipped by solder mask
    Local override; Severity: warning
    @(122.3000 mm, 117.9520 mm): Reference 'TP3'
[silk_over_copper]: Silkscreen clipped by solder mask
    Local override; Severity: warning
    @(103.7000 mm, 103.5000 mm): Reference 'U1'
[silk_over_copper]: Silkscreen clipped by solder mask
    Local override; Severity: warning
    @(110.8300 mm, 117.4000 mm): Reference 'R12'
[silk_over_copper]: Silkscreen clipped by solder mask
    Local override; Severity: warning
    @(122.3000 mm, 114.3520 mm): Reference 'TP1'
[silk_over_copper]: Silkscreen clipped by solder mask
    Local override; Severity: warning
    @(105.0000 mm, 116.1000 mm): Reference 'U4'
[silk_over_copper]: Silkscreen clipped by solder mask
    Local override; Severity: warning
    @(-2.0000 mm, -1.4500 mm): Polygon on F.Silkscreen
[silk_over_copper]: Silkscreen clipped by solder mask
    Local override; Severity: warning
    @(120.5200 mm, 118.8600 mm): Reference 'R14'
[silk_over_copper]: Silkscreen clipped by solder mask
    Local override; Severity: warning
    @(105.5700 mm, 104.4000 mm): Reference 'C3'
[silk_over_copper]: Silkscreen clipped by solder mask
    Local override; Severity: warning
    @(109.8000 mm, 118.5700 mm): Reference 'C22'
[silk_over_copper]: Silkscreen clipped by solder mask
    Local override; Severity: warning
    @(109.3400 mm, 115.0000 mm): Reference 'C19'
[silk_over_copper]: Silkscreen clipped by solder mask
    Local override; Severity: warning
    @(110.5250 mm, 110.7400 mm): Reference 'C13'
[silk_over_copper]: Silkscreen clipped by solder mask
    Local override; Severity: warning
    @(106.9700 mm, 101.8000 mm): Reference 'C7'
[silk_over_copper]: Silkscreen clipped by solder mask
    Local override; Severity: warning
    @(111.0800 mm, 101.6000 mm): Reference 'C11'
[silk_over_copper]: Silkscreen clipped by solder mask
    Local override; Severity: warning
    @(122.4000 mm, 110.6000 mm): Reference 'J2'
[silk_over_copper]: Silkscreen clipped by solder mask
    Local override; Severity: warning
    @(122.4000 mm, 110.6000 mm): Value 'SWD' of J2
[silk_over_copper]: Silkscreen clipped by solder mask
    Local override; Severity: warning
    @(111.0500 mm, 113.0600 mm): Reference 'L2'
[silk_over_copper]: Silkscreen clipped by solder mask
    Local override; Severity: warning
    @(120.2750 mm, 119.6450 mm): Reference 'D1'
[silk_over_copper]: Silkscreen clipped by solder mask
    Local override; Severity: warning
    @(118.7900 mm, 120.3400 mm): Line on F.Silkscreen
[silk_over_copper]: Silkscreen clipped by solder mask
    Local override; Severity: warning
    @(121.0750 mm, 120.3400 mm): Line on F.Silkscreen
[silk_over_copper]: Silkscreen clipped by solder mask
    Local override; Severity: warning
    @(111.4000 mm, 111.3000 mm): Reference 'U2'
[silk_over_copper]: Silkscreen clipped by solder mask
    Local override; Severity: warning
    @(109.2000 mm, 116.4300 mm): Reference 'R9'
[silk_over_copper]: Silkscreen clipped by solder mask
    Local override; Severity: warning
    @(110.8300 mm, 119.2000 mm): Reference 'R13'
[silk_over_copper]: Silkscreen clipped by solder mask
    Local override; Severity: warning
    @(104.3700 mm, 101.5000 mm): Reference 'R2'
[silk_over_copper]: Silkscreen clipped by solder mask
    Local override; Severity: warning
    @(103.0300 mm, 120.7700 mm): Reference 'R5'
[silk_over_copper]: Silkscreen clipped by solder mask
    Local override; Severity: warning
    @(103.9200 mm, 120.9000 mm): Reference 'R6'
[silk_over_copper]: Silkscreen clipped by solder mask
    Local override; Severity: warning
    @(103.3700 mm, 101.5000 mm): Reference 'R1'
[starved_thermal]: Thermal relief connection to zone incomplete (zone min spoke count 2; actual 1)
    Local override; Severity: error
    @(99.5000 mm, 99.5000 mm): Zone [GND] on F.Cu
    @(108.3000 mm, 114.5200 mm): Pad 2 [GND] of C17 on F.Cu
[starved_thermal]: Thermal relief connection to zone incomplete (zone min spoke count 2; actual 1)
    Local override; Severity: error
    @(99.5000 mm, 99.5000 mm): Zone [GND] on F.Cu
    @(113.5000 mm, 103.0500 mm): Pad 4 [GND] of Y1 on F.Cu
[starved_thermal]: Thermal relief connection to zone incomplete (zone min spoke count 2; actual 1)
    Local override; Severity: error
    @(99.5000 mm, 99.5000 mm): Zone [GND] on F.Cu
    @(108.8850 mm, 105.0000 mm): Pad 2 [GND] of C9 on F.Cu
[starved_thermal]: Thermal relief connection to zone incomplete (zone min spoke count 2; actual 1)
    Local override; Severity: error
    @(99.5000 mm, 99.5000 mm): Zone [GND] on F.Cu
    @(102.9500 mm, 104.8500 mm): Pad 1 [GND] of U1 on F.Cu
[starved_thermal]: Thermal relief connection to zone incomplete (zone min spoke count 2; actual 1)
    Local override; Severity: error
    @(99.5000 mm, 99.5000 mm): Zone [GND] on F.Cu
    @(104.4500 mm, 104.8500 mm): Pad 20 [GND] of U1 on F.Cu
[starved_thermal]: Thermal relief connection to zone incomplete (zone min spoke count 2; actual 1)
    Local override; Severity: error
    @(99.5000 mm, 99.5000 mm): Zone [GND] on F.Cu
    @(103.9750 mm, 104.8500 mm): Pad 21 [GND] of U1 on F.Cu
[starved_thermal]: Thermal relief connection to zone incomplete (zone min spoke count 2; actual 1)
    Local override; Severity: error
    @(99.5000 mm, 99.5000 mm): Zone [GND] on F.Cu
    @(110.5000 mm, 114.5200 mm): Pad 2 [GND] of C19 on F.Cu
[starved_thermal]: Thermal relief connection to zone incomplete (zone min spoke count 2; actual 1)
    Local override; Severity: error
    @(99.5000 mm, 99.5000 mm): Zone [GND] on F.Cu
    @(112.2400 mm, 101.1200 mm): Pad 2 [GND] of C11 on F.Cu
[text_height]: Text height out of range (board setup constraints silk text height min height 0.8000 mm; actual 0.7000 mm)
    Rule: board setup constraints silk text height; Severity: warning
    @(111.7000 mm, 111.0000 mm): PCB Text 'discrete-potentiostat 23x22 RevC 6L' on F.Silkscreen
[lib_footprint_issues]: The current configuration does not include the library ''.
    Local override; Severity: warning
    @(109.8000 mm, 118.8000 mm): Footprint R11
[lib_footprint_issues]: The current configuration does not include the library ''.
    Local override; Severity: warning
    @(115.6000 mm, 105.9100 mm): Footprint C33
[lib_footprint_issues]: The current configuration does not include the library ''.
    Local override; Severity: warning
    @(109.8000 mm, 101.8000 mm): Footprint C8
[lib_footprint_issues]: The current configuration does not include the library ''.
    Local override; Severity: warning
    @(121.1000 mm, 109.4000 mm): Footprint C28
[lib_footprint_issues]: The current configuration does not include the library ''.
    Local override; Severity: warning
    @(112.9000 mm, 117.4000 mm): Footprint C23
[lib_footprint_issues]: The current configuration does not include the library ''.
    Local override; Severity: warning
    @(116.1600 mm, 116.3000 mm): Footprint C30
[lib_footprint_issues]: The current configuration does not include the library ''.
    Local override; Severity: warning
    @(108.3000 mm, 115.0000 mm): Footprint C17
[lib_footprint_issues]: The current configuration does not include the library ''.
    Local override; Severity: warning
    @(112.2400 mm, 103.8000 mm): Footprint C32
[lib_footprint_issues]: The current configuration does not include the library ''.
    Local override; Severity: warning
    @(120.0750 mm, 104.0000 mm): Footprint R15
[lib_footprint_issues]: The current configuration does not include the library ''.
    Local override; Severity: warning
    @(111.4000 mm, 115.0000 mm): Footprint R7
[lib_footprint_issues]: The current configuration does not include the library ''.
    Local override; Severity: warning
    @(106.1750 mm, 101.4000 mm): Footprint C2
[lib_footprint_issues]: The current configuration does not include the library ''.
    Local override; Severity: warning
    @(121.1000 mm, 107.6000 mm): Footprint C26
[lib_footprint_issues]: The current configuration does not include the library ''.
    Local override; Severity: warning
    @(113.2000 mm, 115.6500 mm): Footprint C20
[lib_footprint_issues]: The current configuration does not include the library ''.
    Local override; Severity: warning
    @(115.2800 mm, 117.2000 mm): Footprint R10
[lib_footprint_issues]: The current configuration does not include the library ''.
    Local override; Severity: warning
    @(114.2350 mm, 116.4000 mm): Footprint C25
[lib_footprint_issues]: The current configuration does not include the library ''.
    Local override; Severity: warning
    @(116.8000 mm, 110.0000 mm): Footprint U3
[lib_footprint_issues]: The current configuration does not include the library ''.
    Local override; Severity: warning
    @(118.7350 mm, 104.9000 mm): Footprint C35
[lib_footprint_issues]: The current configuration does not include the library ''.
    Local override; Severity: warning
    @(119.5000 mm, 118.5000 mm): Footprint R4
[lib_footprint_issues]: The current configuration does not include the library ''.
    Local override; Severity: warning
    @(111.2000 mm, 101.7000 mm): Footprint C10
[lib_footprint_issues]: The current configuration does not include the library 'pstat'.
    Local override; Severity: warning
    @(101.2000 mm, 114.0000 mm): Footprint L1
[lib_footprint_issues]: The current configuration does not include the library ''.
    Local override; Severity: warning
    @(107.4000 mm, 115.0000 mm): Footprint C16
[lib_footprint_issues]: The current configuration does not include the library ''.
    Local override; Severity: warning
    @(117.0300 mm, 116.3000 mm): Footprint C31
[lib_footprint_issues]: The current configuration does not include the library ''.
    Local override; Severity: warning
    @(114.2300 mm, 114.3200 mm): Footprint L3
[lib_footprint_issues]: The current configuration does not include the library 'pstat'.
    Local override; Severity: warning
    @(105.4000 mm, 121.0000 mm): Footprint J1
[lib_footprint_issues]: The current configuration does not include the library ''.
    Local override; Severity: warning
    @(109.4000 mm, 115.1000 mm): Footprint C18
[lib_footprint_issues]: The current configuration does not include the library ''.
    Local override; Severity: warning
    @(107.6000 mm, 106.4000 mm): Footprint C6
[lib_footprint_issues]: The current configuration does not include the library ''.
    Local override; Severity: warning
    @(117.0000 mm, 120.4000 mm): Footprint U6
[lib_footprint_issues]: The current configuration does not include the library ''.
    Local override; Severity: warning
    @(110.1700 mm, 104.4000 mm): Footprint C5
[lib_footprint_issues]: The current configuration does not include the library ''.
    Local override; Severity: warning
    @(107.6000 mm, 104.4000 mm): Footprint C4
[lib_footprint_issues]: The current configuration does not include the library ''.
    Local override; Severity: warning
    @(111.2050 mm, 104.6000 mm): Footprint C27
[lib_footprint_issues]: The current configuration does not include the library ''.
    Local override; Severity: warning
    @(114.6000 mm, 103.9000 mm): Footprint Y1
[lib_footprint_issues]: The current configuration does not include the library ''.
    Local override; Severity: warning
    @(122.3000 mm, 117.8000 mm): Footprint TP2
[lib_footprint_issues]: The current configuration does not include the library ''.
    Local override; Severity: warning
    @(121.1000 mm, 111.2000 mm): Footprint C29
[lib_footprint_issues]: The current configuration does not include the library ''.
    Local override; Severity: warning
    @(108.8850 mm, 105.9500 mm): Footprint C9
[lib_footprint_issues]: The current configuration does not include the library ''.
    Local override; Severity: warning
    @(112.9000 mm, 119.2000 mm): Footprint C24
[lib_footprint_issues]: The current configuration does not include the library ''.
    Local override; Severity: warning
    @(121.4150 mm, 104.9000 mm): Footprint C34
[lib_footprint_issues]: The current configuration does not include the library ''.
    Local override; Severity: warning
    @(114.6000 mm, 119.4000 mm): Footprint C21
[lib_footprint_issues]: The current configuration does not include the library ''.
    Local override; Severity: warning
    @(109.4000 mm, 111.1350 mm): Footprint C12
[lib_footprint_issues]: The current configuration does not include the library ''.
    Local override; Severity: warning
    @(112.3000 mm, 115.5900 mm): Footprint R8
[lib_footprint_issues]: The current configuration does not include the library 'pstat'.
    Local override; Severity: warning
    @(119.4000 mm, 100.9500 mm): Footprint E1
[lib_footprint_issues]: The current configuration does not include the library 'pstat'.
    Local override; Severity: warning
    @(117.7000 mm, 104.0000 mm): Footprint FL1
[lib_footprint_issues]: The current configuration does not include the library ''.
    Local override; Severity: warning
    @(122.3000 mm, 119.6000 mm): Footprint TP3
[lib_footprint_issues]: The current configuration does not include the library ''.
    Local override; Severity: warning
    @(103.7000 mm, 107.0000 mm): Footprint U1
[lib_footprint_issues]: The current configuration does not include the library ''.
    Local override; Severity: warning
    @(112.0000 mm, 117.4000 mm): Footprint R12
[lib_footprint_issues]: The current configuration does not include the library ''.
    Local override; Severity: warning
    @(122.3000 mm, 116.0000 mm): Footprint TP1
[lib_footprint_issues]: The current configuration does not include the library ''.
    Local override; Severity: warning
    @(105.0000 mm, 118.6000 mm): Footprint U4
[lib_footprint_issues]: The current configuration does not include the library ''.
    Local override; Severity: warning
    @(108.7400 mm, 112.7000 mm): Footprint C14
[lib_footprint_issues]: The current configuration does not include the library ''.
    Local override; Severity: warning
    @(104.6000 mm, 115.6000 mm): Footprint U5
[lib_footprint_issues]: The current configuration does not include the library ''.
    Local override; Severity: warning
    @(120.5200 mm, 120.0300 mm): Footprint R14
[lib_footprint_issues]: The current configuration does not include the library ''.
    Local override; Severity: warning
    @(106.7300 mm, 104.4000 mm): Footprint C3
[lib_footprint_issues]: The current configuration does not include the library ''.
    Local override; Severity: warning
    @(109.8000 mm, 120.0000 mm): Footprint C22
[lib_footprint_issues]: The current configuration does not include the library ''.
    Local override; Severity: warning
    @(110.5000 mm, 115.0000 mm): Footprint C19
[lib_footprint_issues]: The current configuration does not include the library ''.
    Local override; Severity: warning
    @(110.5250 mm, 112.1700 mm): Footprint C13
[lib_footprint_issues]: The current configuration does not include the library ''.
    Local override; Severity: warning
    @(108.4000 mm, 101.8000 mm): Footprint C7
[lib_footprint_issues]: The current configuration does not include the library ''.
    Local override; Severity: warning
    @(112.2400 mm, 101.6000 mm): Footprint C11
[lib_footprint_issues]: The current configuration does not include the library 'pstat'.
    Local override; Severity: warning
    @(122.4000 mm, 110.6000 mm): Footprint J2
[lib_footprint_issues]: The current configuration does not include the library ''.
    Local override; Severity: warning
    @(112.6000 mm, 113.0600 mm): Footprint L2
[lib_footprint_issues]: The current configuration does not include the library ''.
    Local override; Severity: warning
    @(120.2750 mm, 121.0750 mm): Footprint D1
[lib_footprint_issues]: The current configuration does not include the library ''.
    Local override; Severity: warning
    @(111.4000 mm, 108.9000 mm): Footprint U2
[lib_footprint_issues]: The current configuration does not include the library ''.
    Local override; Severity: warning
    @(109.2000 mm, 117.6000 mm): Footprint R9
[lib_footprint_issues]: The current configuration does not include the library ''.
    Local override; Severity: warning
    @(102.6500 mm, 102.1500 mm): Footprint C1
[lib_footprint_issues]: The current configuration does not include the library ''.
    Local override; Severity: warning
    @(112.0000 mm, 119.2000 mm): Footprint R13
[lib_footprint_issues]: The current configuration does not include the library ''.
    Local override; Severity: warning
    @(103.2000 mm, 101.5000 mm): Footprint R2
[lib_footprint_issues]: The current configuration does not include the library ''.
    Local override; Severity: warning
    @(101.8600 mm, 120.7700 mm): Footprint R5
[lib_footprint_issues]: The current configuration does not include the library ''.
    Local override; Severity: warning
    @(103.7000 mm, 120.9000 mm): Footprint C15
[lib_footprint_issues]: The current configuration does not include the library ''.
    Local override; Severity: warning
    @(104.2000 mm, 101.5000 mm): Footprint TH1
[lib_footprint_issues]: The current configuration does not include the library 'pstat'.
    Local override; Severity: warning
    @(111.7000 mm, 111.2500 mm): Footprint BT1
[lib_footprint_issues]: The current configuration does not include the library ''.
    Local override; Severity: warning
    @(120.5000 mm, 120.5000 mm): Footprint R3
[lib_footprint_issues]: The current configuration does not include the library ''.
    Local override; Severity: warning
    @(102.7500 mm, 120.9000 mm): Footprint R6
[lib_footprint_issues]: The current configuration does not include the library ''.
    Local override; Severity: warning
    @(102.2000 mm, 101.5000 mm): Footprint R1
[silk_edge_clearance]: Silkscreen clipped by board edge
    Rule: board setup constraints silk; Severity: warning
    @(101.5000 mm, 100.0000 mm): Line on Edge.Cuts
    @(106.1750 mm, 99.9700 mm): Reference 'C2'
[silk_edge_clearance]: Silkscreen clipped by board edge
    Rule: board setup constraints silk; Severity: warning
    @(100.0000 mm, 120.5000 mm): Line on Edge.Cuts
    @(101.2000 mm, 114.0000 mm): Value 'WR202010-18M8-ID 11uH' of L1
[silk_edge_clearance]: Silkscreen clipped by board edge
    Rule: board setup constraints silk; Severity: warning
    @(101.5000 mm, 120.5000 mm): Arc on Edge.Cuts
    @(105.4000 mm, 121.0000 mm): Value 'ELECTRODES' of J1
[silk_edge_clearance]: Silkscreen clipped by board edge
    Rule: board setup constraints silk; Severity: warning
    @(121.9000 mm, 122.0000 mm): Line on Edge.Cuts
    @(117.0000 mm, 121.9600 mm): Line on F.Silkscreen
[silk_edge_clearance]: Silkscreen clipped by board edge
    Rule: board setup constraints silk; Severity: warning
    @(121.9000 mm, 122.0000 mm): Line on Edge.Cuts
    @(117.0000 mm, 121.9600 mm): Line on F.Silkscreen
[silk_edge_clearance]: Silkscreen clipped by board edge
    Rule: board setup constraints silk; Severity: warning
    @(123.4000 mm, 101.5000 mm): Line on Edge.Cuts
    @(122.3000 mm, 116.1520 mm): Reference 'TP2'
[silk_edge_clearance]: Silkscreen clipped by board edge
    Rule: board setup constraints silk; Severity: warning
    @(101.5000 mm, 100.0000 mm): Line on Edge.Cuts
    @(119.4000 mm, 100.9500 mm): Reference 'E1'
[silk_edge_clearance]: Silkscreen clipped by board edge
    Rule: board setup constraints silk; Severity: warning
    @(101.5000 mm, 100.0000 mm): Line on Edge.Cuts
    @(119.4000 mm, 100.9500 mm): Value '2450AT07A0100' of E1
[silk_edge_clearance]: Silkscreen clipped by board edge
    Rule: board setup constraints silk; Severity: warning
    @(123.4000 mm, 101.5000 mm): Line on Edge.Cuts
    @(117.7000 mm, 104.0000 mm): Value '2450FM07A0029' of FL1
[silk_edge_clearance]: Silkscreen clipped by board edge
    Rule: board setup constraints silk; Severity: warning
    @(123.4000 mm, 101.5000 mm): Line on Edge.Cuts
    @(122.3000 mm, 117.9520 mm): Reference 'TP3'
[silk_edge_clearance]: Silkscreen clipped by board edge
    Rule: board setup constraints silk; Severity: warning
    @(123.4000 mm, 101.5000 mm): Line on Edge.Cuts
    @(122.3000 mm, 114.3520 mm): Reference 'TP1'
[silk_edge_clearance]: Silkscreen clipped by board edge
    Rule: board setup constraints silk; Severity: warning
    @(101.5000 mm, 100.0000 mm): Line on Edge.Cuts
    @(102.6500 mm, 99.8500 mm): Reference 'C1'
[silk_edge_clearance]: Silkscreen clipped by board edge
    Rule: board setup constraints silk; Severity: warning
    @(121.9000 mm, 122.0000 mm): Line on Edge.Cuts
    @(104.8600 mm, 120.9000 mm): Reference 'C15'
[courtyards_overlap]: Courtyards overlap
    Rule: board setup constraints courtyard; Severity: error
    @(109.8000 mm, 118.8000 mm): Footprint R11
    @(105.0000 mm, 118.6000 mm): Footprint U4
[courtyards_overlap]: Courtyards overlap
    Rule: board setup constraints courtyard; Severity: error
    @(109.8000 mm, 118.8000 mm): Footprint R11
    @(109.8000 mm, 120.0000 mm): Footprint C22
[courtyards_overlap]: Courtyards overlap
    Rule: board setup constraints courtyard; Severity: error
    @(115.6000 mm, 105.9100 mm): Footprint C33
    @(114.6000 mm, 103.9000 mm): Footprint Y1
[courtyards_overlap]: Courtyards overlap
    Rule: board setup constraints courtyard; Severity: error
    @(109.8000 mm, 101.8000 mm): Footprint C8
    @(111.2000 mm, 101.7000 mm): Footprint C10
[courtyards_overlap]: Courtyards overlap
    Rule: board setup constraints courtyard; Severity: error
    @(109.8000 mm, 101.8000 mm): Footprint C8
    @(111.2050 mm, 104.6000 mm): Footprint C27
[courtyards_overlap]: Courtyards overlap
    Rule: board setup constraints courtyard; Severity: error
    @(109.8000 mm, 101.8000 mm): Footprint C8
    @(108.4000 mm, 101.8000 mm): Footprint C7
[courtyards_overlap]: Courtyards overlap
    Rule: board setup constraints courtyard; Severity: error
    @(121.1000 mm, 109.4000 mm): Footprint C28
    @(121.1000 mm, 107.6000 mm): Footprint C26
[courtyards_overlap]: Courtyards overlap
    Rule: board setup constraints courtyard; Severity: error
    @(121.1000 mm, 109.4000 mm): Footprint C28
    @(121.1000 mm, 111.2000 mm): Footprint C29
[courtyards_overlap]: Courtyards overlap
    Rule: board setup constraints courtyard; Severity: error
    @(112.9000 mm, 117.4000 mm): Footprint C23
    @(113.2000 mm, 115.6500 mm): Footprint C20
[courtyards_overlap]: Courtyards overlap
    Rule: board setup constraints courtyard; Severity: error
    @(112.9000 mm, 117.4000 mm): Footprint C23
    @(112.9000 mm, 119.2000 mm): Footprint C24
[courtyards_overlap]: Courtyards overlap
    Rule: board setup constraints courtyard; Severity: error
    @(112.9000 mm, 117.4000 mm): Footprint C23
    @(112.3000 mm, 115.5900 mm): Footprint R8
[courtyards_overlap]: Courtyards overlap
    Rule: board setup constraints courtyard; Severity: error
    @(112.9000 mm, 117.4000 mm): Footprint C23
    @(112.0000 mm, 117.4000 mm): Footprint R12
[courtyards_overlap]: Courtyards overlap
    Rule: board setup constraints courtyard; Severity: error
    @(112.9000 mm, 117.4000 mm): Footprint C23
    @(112.0000 mm, 119.2000 mm): Footprint R13
[courtyards_overlap]: Courtyards overlap
    Rule: board setup constraints courtyard; Severity: error
    @(116.1600 mm, 116.3000 mm): Footprint C30
    @(115.2800 mm, 117.2000 mm): Footprint R10
[courtyards_overlap]: Courtyards overlap
    Rule: board setup constraints courtyard; Severity: error
    @(116.1600 mm, 116.3000 mm): Footprint C30
    @(117.0300 mm, 116.3000 mm): Footprint C31
[courtyards_overlap]: Courtyards overlap
    Rule: board setup constraints courtyard; Severity: error
    @(108.3000 mm, 115.0000 mm): Footprint C17
    @(107.4000 mm, 115.0000 mm): Footprint C16
[courtyards_overlap]: Courtyards overlap
    Rule: board setup constraints courtyard; Severity: error
    @(108.3000 mm, 115.0000 mm): Footprint C17
    @(109.4000 mm, 115.1000 mm): Footprint C18
[courtyards_overlap]: Courtyards overlap
    Rule: board setup constraints courtyard; Severity: error
    @(112.2400 mm, 103.8000 mm): Footprint C32
    @(111.2000 mm, 101.7000 mm): Footprint C10
[courtyards_overlap]: Courtyards overlap
    Rule: board setup constraints courtyard; Severity: error
    @(112.2400 mm, 103.8000 mm): Footprint C32
    @(111.2050 mm, 104.6000 mm): Footprint C27
[courtyards_overlap]: Courtyards overlap
    Rule: board setup constraints courtyard; Severity: error
    @(112.2400 mm, 103.8000 mm): Footprint C32
    @(114.6000 mm, 103.9000 mm): Footprint Y1
[courtyards_overlap]: Courtyards overlap
    Rule: board setup constraints courtyard; Severity: error
    @(120.0750 mm, 104.0000 mm): Footprint R15
    @(118.7350 mm, 104.9000 mm): Footprint C35
[courtyards_overlap]: Courtyards overlap
    Rule: board setup constraints courtyard; Severity: error
    @(120.0750 mm, 104.0000 mm): Footprint R15
    @(121.4150 mm, 104.9000 mm): Footprint C34
[courtyards_overlap]: Courtyards overlap
    Rule: board setup constraints courtyard; Severity: error
    @(111.4000 mm, 115.0000 mm): Footprint R7
    @(112.3000 mm, 115.5900 mm): Footprint R8
[courtyards_overlap]: Courtyards overlap
    Rule: board setup constraints courtyard; Severity: error
    @(111.4000 mm, 115.0000 mm): Footprint R7
    @(110.5000 mm, 115.0000 mm): Footprint C19
[courtyards_overlap]: Courtyards overlap
    Rule: board setup constraints courtyard; Severity: error
    @(111.4000 mm, 115.0000 mm): Footprint R7
    @(112.6000 mm, 113.0600 mm): Footprint L2
[courtyards_overlap]: Courtyards overlap
    Rule: board setup constraints courtyard; Severity: error
    @(106.1750 mm, 101.4000 mm): Footprint C2
    @(102.6500 mm, 102.1500 mm): Footprint C1
[courtyards_overlap]: Courtyards overlap
    Rule: board setup constraints courtyard; Severity: error
    @(113.2000 mm, 115.6500 mm): Footprint C20
    @(114.2350 mm, 116.4000 mm): Footprint C25
[courtyards_overlap]: Courtyards overlap
    Rule: board setup constraints courtyard; Severity: error
    @(113.2000 mm, 115.6500 mm): Footprint C20
    @(114.2300 mm, 114.3200 mm): Footprint L3
[courtyards_overlap]: Courtyards overlap
    Rule: board setup constraints courtyard; Severity: error
    @(113.2000 mm, 115.6500 mm): Footprint C20
    @(112.3000 mm, 115.5900 mm): Footprint R8
[courtyards_overlap]: Courtyards overlap
    Rule: board setup constraints courtyard; Severity: error
    @(113.2000 mm, 115.6500 mm): Footprint C20
    @(112.6000 mm, 113.0600 mm): Footprint L2
[courtyards_overlap]: Courtyards overlap
    Rule: board setup constraints courtyard; Severity: error
    @(115.2800 mm, 117.2000 mm): Footprint R10
    @(114.2350 mm, 116.4000 mm): Footprint C25
[courtyards_overlap]: Courtyards overlap
    Rule: board setup constraints courtyard; Severity: error
    @(116.8000 mm, 110.0000 mm): Footprint U3
    @(112.6000 mm, 113.0600 mm): Footprint L2
[courtyards_overlap]: Courtyards overlap
    Rule: board setup constraints courtyard; Severity: error
    @(116.8000 mm, 110.0000 mm): Footprint U3
    @(111.4000 mm, 108.9000 mm): Footprint U2
[courtyards_overlap]: Courtyards overlap
    Rule: board setup constraints courtyard; Severity: error
    @(119.5000 mm, 118.5000 mm): Footprint R4
    @(117.0000 mm, 120.4000 mm): Footprint U6
[courtyards_overlap]: Courtyards overlap
    Rule: board setup constraints courtyard; Severity: error
    @(111.2000 mm, 101.7000 mm): Footprint C10
    @(111.2050 mm, 104.6000 mm): Footprint C27
[courtyards_overlap]: Courtyards overlap
    Rule: board setup constraints courtyard; Severity: error
    @(111.2000 mm, 101.7000 mm): Footprint C10
    @(112.2400 mm, 101.6000 mm): Footprint C11
[courtyards_overlap]: Courtyards overlap
    Rule: board setup constraints courtyard; Severity: error
    @(114.2300 mm, 114.3200 mm): Footprint L3
    @(112.6000 mm, 113.0600 mm): Footprint L2
[courtyards_overlap]: Courtyards overlap
    Rule: board setup constraints courtyard; Severity: error
    @(109.4000 mm, 115.1000 mm): Footprint C18
    @(110.5000 mm, 115.0000 mm): Footprint C19
[courtyards_overlap]: Courtyards overlap
    Rule: board setup constraints courtyard; Severity: error
    @(107.6000 mm, 106.4000 mm): Footprint C6
    @(108.8850 mm, 105.9500 mm): Footprint C9
[courtyards_overlap]: Courtyards overlap
    Rule: board setup constraints courtyard; Severity: error
    @(117.0000 mm, 120.4000 mm): Footprint U6
    @(114.6000 mm, 119.4000 mm): Footprint C21
[courtyards_overlap]: Courtyards overlap
    Rule: board setup constraints courtyard; Severity: error
    @(117.0000 mm, 120.4000 mm): Footprint U6
    @(120.2750 mm, 121.0750 mm): Footprint D1
[courtyards_overlap]: Courtyards overlap
    Rule: board setup constraints courtyard; Severity: error
    @(110.1700 mm, 104.4000 mm): Footprint C5
    @(111.2050 mm, 104.6000 mm): Footprint C27
[courtyards_overlap]: Courtyards overlap
    Rule: board setup constraints courtyard; Severity: error
    @(110.1700 mm, 104.4000 mm): Footprint C5
    @(108.8850 mm, 105.9500 mm): Footprint C9
[courtyards_overlap]: Courtyards overlap
    Rule: board setup constraints courtyard; Severity: error
    @(107.6000 mm, 104.4000 mm): Footprint C4
    @(108.8850 mm, 105.9500 mm): Footprint C9
[courtyards_overlap]: Courtyards overlap
    Rule: board setup constraints courtyard; Severity: error
    @(107.6000 mm, 104.4000 mm): Footprint C4
    @(106.7300 mm, 104.4000 mm): Footprint C3
[courtyards_overlap]: Courtyards overlap
    Rule: board setup constraints courtyard; Severity: error
    @(114.6000 mm, 103.9000 mm): Footprint Y1
    @(112.2400 mm, 101.6000 mm): Footprint C11
[courtyards_overlap]: Courtyards overlap
    Rule: board setup constraints courtyard; Severity: error
    @(122.3000 mm, 117.8000 mm): Footprint TP2
    @(122.3000 mm, 119.6000 mm): Footprint TP3
[courtyards_overlap]: Courtyards overlap
    Rule: board setup constraints courtyard; Severity: error
    @(122.3000 mm, 117.8000 mm): Footprint TP2
    @(122.3000 mm, 116.0000 mm): Footprint TP1
[courtyards_overlap]: Courtyards overlap
    Rule: board setup constraints courtyard; Severity: error
    @(108.8850 mm, 105.9500 mm): Footprint C9
    @(111.4000 mm, 108.9000 mm): Footprint U2
[courtyards_overlap]: Courtyards overlap
    Rule: board setup constraints courtyard; Severity: error
    @(112.9000 mm, 119.2000 mm): Footprint C24
    @(112.0000 mm, 117.4000 mm): Footprint R12
[courtyards_overlap]: Courtyards overlap
    Rule: board setup constraints courtyard; Severity: error
    @(112.9000 mm, 119.2000 mm): Footprint C24
    @(112.0000 mm, 119.2000 mm): Footprint R13
[courtyards_overlap]: Courtyards overlap
    Rule: board setup constraints courtyard; Severity: error
    @(109.4000 mm, 111.1350 mm): Footprint C12
    @(110.5250 mm, 112.1700 mm): Footprint C13
[courtyards_overlap]: Courtyards overlap
    Rule: board setup constraints courtyard; Severity: error
    @(112.3000 mm, 115.5900 mm): Footprint R8
    @(112.0000 mm, 117.4000 mm): Footprint R12
[courtyards_overlap]: Courtyards overlap
    Rule: board setup constraints courtyard; Severity: error
    @(112.3000 mm, 115.5900 mm): Footprint R8
    @(112.6000 mm, 113.0600 mm): Footprint L2
[courtyards_overlap]: Courtyards overlap
    Rule: board setup constraints courtyard; Severity: error
    @(122.3000 mm, 119.6000 mm): Footprint TP3
    @(120.5200 mm, 120.0300 mm): Footprint R14
[courtyards_overlap]: Courtyards overlap
    Rule: board setup constraints courtyard; Severity: error
    @(122.3000 mm, 119.6000 mm): Footprint TP3
    @(120.2750 mm, 121.0750 mm): Footprint D1
[courtyards_overlap]: Courtyards overlap
    Rule: board setup constraints courtyard; Severity: error
    @(112.0000 mm, 117.4000 mm): Footprint R12
    @(112.0000 mm, 119.2000 mm): Footprint R13
[courtyards_overlap]: Courtyards overlap
    Rule: board setup constraints courtyard; Severity: error
    @(105.0000 mm, 118.6000 mm): Footprint U4
    @(104.6000 mm, 115.6000 mm): Footprint U5
[courtyards_overlap]: Courtyards overlap
    Rule: board setup constraints courtyard; Severity: error
    @(105.0000 mm, 118.6000 mm): Footprint U4
    @(109.8000 mm, 120.0000 mm): Footprint C22
[courtyards_overlap]: Courtyards overlap
    Rule: board setup constraints courtyard; Severity: error
    @(105.0000 mm, 118.6000 mm): Footprint U4
    @(109.2000 mm, 117.6000 mm): Footprint R9
[courtyards_overlap]: Courtyards overlap
    Rule: board setup constraints courtyard; Severity: error
    @(108.7400 mm, 112.7000 mm): Footprint C14
    @(110.5250 mm, 112.1700 mm): Footprint C13
[courtyards_overlap]: Courtyards overlap
    Rule: board setup constraints courtyard; Severity: error
    @(120.5200 mm, 120.0300 mm): Footprint R14
    @(120.2750 mm, 121.0750 mm): Footprint D1
[courtyards_overlap]: Courtyards overlap
    Rule: board setup constraints courtyard; Severity: error
    @(110.5250 mm, 112.1700 mm): Footprint C13
    @(112.6000 mm, 113.0600 mm): Footprint L2
[courtyards_overlap]: Courtyards overlap
    Rule: board setup constraints courtyard; Severity: error
    @(101.8600 mm, 120.7700 mm): Footprint R5
    @(102.7500 mm, 120.9000 mm): Footprint R6

** Found 0 unconnected pads **

** Found 0 Footprint errors **

** End of Report **

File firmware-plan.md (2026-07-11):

# 펌웨어 포팅 계획 (기존 `firmware/` → 디스크리트 AFE)

> **✅ 구현 완료 (2026-07-11)** — `firmware/` 폴더에 구현됨. 이 문서는 계획 원문(이력).
> 실제 프로토콜/파라미터/캘리브레이션 절차는 `firmware/README.md` 참조.

측정 방식이 근본적으로 다르다: 기존은 **AD5941이 측정하고 nRF는 SPI로 결과를 받아오는 구조**,
새 설계는 **nRF 자신이 ADC(SAADC)가 되어 직접 측정하는 구조**다.
따라서 측정 코어(아래 "신규 작성")는 포팅이 아니라 **완전 신규 코드**다 — AD5941 관련
코드(SPI, 시퀀서, 레지스터 제어)는 한 줄도 남지 않는다.

다만 기존 펌웨어에서 측정 코어는 "샘플 하나(전류, 타임스탬프)를 상위로 넘기는" 인터페이스로
앱 계층과 분리되어 있으므로, BLE/버퍼링/런 모드/프로토콜 계층은 수정 없이 재사용된다.

## 그대로 재사용

- NUS 기반 JSON 프로토콜 (`start`/`stop`/`config`/`ack`/`status`)
- `{"d":[[seq,t_ms,current_nA,range],...]}` 스트리밍 포맷 — `range` 필드는 SAADC 게인 인덱스로 의미만 변경
- 무손실 링버퍼 + seq/ACK 재전송
- 전력 인지형 BLE 커넥션 인터벌 (측정 중 fast / 대기 slow)
- 런 모드: 연속 / 타이머 / 사이클
- Android 앱 전체 (프로토콜 동일하므로 무수정)

## 제거

- `src/ad5940lib/` (벤더 드라이버) 및 SPI 버스 설정
- AD5941 초기화/시퀀서/LPTIA 오토레인지 코드

## 신규 작성

### 1. AFE 제어 (GPIO)
- `AFE_PWR` GPIO (고드라이브): 측정 시작 시 HIGH → REF/LPV802 급전 (AFE 합계 ~2 µA),
  안정화 대기 ~50 ms 후 샘플링 시작. 정지 시 LOW (전극 분극 방지 + 소모 0).

### 2. SAADC 측정 엔진
- 차동 채널: AIN+ = TIA_OUT, AIN− = 1.024 V 노드
- 타이머(RTC) 트리거 주기 샘플링, 하드웨어 오버샘플링 최대 활용 + 필요 시 소프트웨어 평균
- 변환: `current_nA = (code × LSB_nV[gain]) / RF_MΩ` (캘리브레이션 계수 적용)
- acquisition time 40 µs (1 kΩ 소스 임피던스 대응)

### 3. 게인 오토레인지 (AD5941 오토레인지 대체)
- 게인 테이블: {1/2, 1, 4} → range 인덱스 {0, 1, 2}
- |ΔV| > 85% FS → 게인 다운 / < 20% FS → 게인 업 (히스테리시스)
- 전환 직후 첫 샘플 폐기

### 3.5 RF/오버샘플링은 하드코딩 금지 — 런타임 설정값

RF와 CF는 보드에서 언제든 교체될 수 있는 부품이므로, 펌웨어가 RF에 의존하는 지점을
전부 설정값으로 뺀다:

- `rf_ohm` (전류 환산 `I = ΔV/RF` 및 게인 전환 임계값 계산에 사용)
- `oversample` (RF가 클수록 신호가 커져 낮춰도 됨: 1 MΩ→64×, 5.1 MΩ→16×, 10 MΩ→4× 수준)

둘 다 NVM(Settings) 저장 + BLE `config` 명령으로 변경 가능하게 한다.
→ RF 교체 절차 = ① 새 RF/CF 납땜 ② BLE로 `rf_ohm` 전송 ③ 더미셀 캘리브레이션 1회.
   펌웨어 재빌드/리플래시 불필요.

### 4. 캘리브레이션
- 더미셀(기지 저항 1.00 MΩ, 이론 전류 0.512 µA)로 게인별 스케일 보정
- 셀 오픈 상태에서 오프셋(제로 전류) 측정
- 계수는 NVM(Settings subsystem) 저장

### 5. 배터리 관리 (신규 — LIR2032는 맨셀)
- VBAT 분압 채널 주기 측정, `status` JSON에 전압 포함
- < 3.3 V: 앱에 low-batt 경고 / 측정 시작 거부
- < 3.0 V: 데이터 플러시 후 System OFF (과방전 보호)
- 충전 중(MCP73832 STAT → P0.08, 오픈드레인+풀업) 측정 시작 시 노이즈 경고

## 보드 오버레이

- SPI 노드 삭제, `zephyr,user`에 SAADC 채널(차동 2입력 + VBAT) / AFE_PWR / CHG GPIO 정의
- 칩다운 보드: 32.768 kHz 크리스탈 없음 → `CONFIG_CLOCK_CONTROL_NRF_K32SRC_RC=y` (+주기 캘리브레이션), DC/DC 인덕터 실장됨 → `CONFIG_BOARD_ENABLE_DCDC=y`로 전력 절감
- 모듈 변경 시(MDBT42Q → ANNA-B112 등) 핀맵만 교체

## 검증 순서

1. 더미셀(저항+커패시터)로 스텝 응답 — TIA 안정성(발진 여부), CF 값 확정
2. 기지 저항 3점(100 k / 1 M / 10 M)으로 게인별 선형성·오토레인지 전환 확인
3. 페로시안화칼륨 등 표준 산화환원계로 실제 CA 곡선 vs AD5941 보드 교차 비교
4. 충전 중 노이즈 플로어 측정 → "충전 중 측정 금지" 정책 확정

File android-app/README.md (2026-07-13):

# Ampero — 안드로이드 앱 (WebView 하이브리드)

웨어러블 포텐쇼스탯(pstat) 전용 안드로이드 앱. 검증된 목업 UI(`../app/mockup.html`)를
그대로 앱 자산으로 싣고, **네이티브 BLE 계층**을 JS 브리지로 연결한 하이브리드 구조.

## 구조

```
app/src/main/
  assets/app.html                     ← UI 전체 (목업 v1.1 + 라이브 BLE 브리지)
  java/com/ampero/pstat/
    MainActivity.kt                    ← WebView 호스트 + 런타임 BT 권한
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

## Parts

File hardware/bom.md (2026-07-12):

# BOM

레퍼런스는 `hardware/kicad/discrete-potentiostat.kicad_sch`와 1:1 일치.

## IC / 모듈 / 배터리 / 기구

| Ref | 부품 | 패키지 | 역할 |
|---|---|---|---|
| U1 | BQ51013BRHLR | VQFN-20 (RHL) | Qi 수신, 레귤레이티드 5 V 출력 |
| U6 | MCP73832T-2ACI/OT | SOT-23-5 | 리튬 충전기 4.2 V / 20 mA, 종지 ~1.5 mA |
| U2 | MIC5205-3.3YM5 | SOT-23-5 | 3.3 V LDO |
| U3 | nRF52832-QFAA | QFN48 6×6 (칩다운) | MCU + BLE + SAADC |
| Y1 | 수정 32 MHz, CL 8 pF, ±10 ppm | 3225 | HFXO (BLE 필수) |
| FL1 | Johanson 2450FM07A0029 | 0402 4-pin | nRF52 전용 임피던스 매칭 LPF (디스크리트 매칭 대체) |
| E1 | Johanson 2450AT07A0100 | **1.0×0.5×0.37 mm (0402), 4단자** | 2.4 GHz 칩안테나 — 단자 1·4=Feed, **2·3=GND**(데이터시트 36S0021A Rev4.1 확정, 좌측 GND 포어에 스트립 연결). 전층 구리금지 ~5×3 mm 킵아웃 + pi 슬롯(C35/R15/C34) 실보드 튜닝 필수 |
| U4 | LPV802DGKR | VSSOP-8 | A: 컨트롤 앰프 / B: TIA — 나노파워 0.32 µA/ch, Ib 0.1 pA |
| U5 | REF35102QDBVR | SOT-23-6 | 1.024 V 레퍼런스 |
| BT1 | LIR2032 **탭 용접형(솔더탭)** | 뒷면 패드 2개 | 3.7 V / ~40 mAh — Keystone 3034 홀더는 폭 27 mm로 23.4×22 mm 보드에 안 들어가 탭셀 채택 (뒷면 중앙 Ø21 배치구역 확보). 보호회로 없음 — 펌웨어 컷오프 필수 |
| L1 | TDK WR202010-18M8-ID | **20×20×1.0 mm** | Qi RX 코일, **11 µH ±5%**, DCR 350 mΩ, ~$3.6 |
| D1 | LED GREEN 0603 | — | 상태 표시 (P0.07) |
| J1 | 납땜 패드 Ø1.0 mm ×3 | 피치 1.8 mm | 전극 CE/RE/WE 와이어 직납 |
| J2 | 납땜 패드 Ø1.0 mm ×5 | 피치 1.8 mm | SWD 와이어 직납 (3V3/SWDIO/SWDCLK/RESET/GND) |
| TP1–TP3 | 테스트포인트 | Ø1.5 mm | VREF / TIA_OUT / VBIAS |

## 수동소자 (회로도 Ref 순)

| Ref | 값 | 사양 | 역할 |
|---|---|---|---|
| C1 | 220 nF | C0G 50 V, 1210 | 직렬 공진 (fs≈102 kHz, L=11 µH 기준) |
| C2 | 2.2 nF | C0G 50 V | 병렬 공진 (fd≈1 MHz) |
| C3, C4 | 10 nF | 25 V | BOOT1/BOOT2 → AC1/AC2 |
| C5, C6 | 22 nF | 25 V | COMM1/COMM2 → AC1/AC2 |
| C7, C8 | 470 nF | 25 V | CLAMP1/CLAMP2 → AC1/AC2 |
| C9 | 10 µF | 25 V, 0805 | RECT |
| C10, C11 | 4.7 µF + 100 nF | 10 V | V5OUT (BQ51013B OUT = MCP73832 입력) |
| C12 | 1 µF | 10 V | LDO 입력 |
| C13 | 2.2 µF | 10 V | LDO 출력 (세라믹, ≥1 µF) |
| C14 | 470 pF | — | MIC5205 BYP (노이즈 저감) |
| C15 | 100 nF | — | VBAT_DIV 필터 |
| C16, C17 | 100 nF + 1 µF | — | AFE_PWR 디커플링 |
| C18 | 1 µF | 저누설 | REF35 NR (2.7 Hz LPF) |
| C19 | 100 nF | — | VREF 출력 (REF35 최소 0.1 µF) |
| C20 | 100 nF | — | VBIAS(0.512 V) 필터 |
| C21 | 1 nF | **DNP** | 컨트롤 앰프 보상 (발진 시만 실장) |
| C22 | 470 pF | C0G | CF — TIA 대역제한 (RF 교체 시 짝 교체) |
| C23, C24 | 10 nF | C0G | SAADC 입력 RC |
| C25 | 4.7 µF | 10 V | VDD 벌크 |
| C26, C28, C29 | 100 nF ×3 | — | VDD 핀 13/36/48 디커플링 |
| C30 | 100 nF | — | DEC1 |
| C31 | 1 µF | — | DEC4 (DC/DC 출력) |
| C32, C33 | 12 pF ×2 | C0G | 32 MHz 로드캡 (CL 8 pF 기준) |
| C34, C35 | (DNP) ×2 | C0G | 안테나 pi 튜닝 션트 슬롯 |
| C27 | 4.7 µF | 10 V | 배터리(+BATT) 측 |
| R1 | 2.32 kΩ | 1% | ILIM 상단 — IMAX = 250/(R1+R2) ≈ 100 mA (5V 출력 전류 한도) |
| R2 | 200 Ω | 1% | RFOD (FOD 탭, 캘리브레이션 시작값) |
| R3 | 49.9 kΩ | 1% | MCP73832 PROG — ICHG = 1000/RPROG = 20 mA |
| R4 | 100 kΩ | — | /CHG 풀업 → 3V3 |
| R5, R6 | 1 MΩ ×2 | 1% | VBAT 모니터 분압 → AIN2 |
| R7, R8 | 1 MΩ ×2 | 1% 페어 | 1:1 바이어스 분압 → VBIAS 0.512 V |
| R9 | 100 Ω | — | CE 직렬 (안정성) |
| R10 | 1 kΩ | **DNP** | 컨트롤 앰프 보상 (C21과 직렬) |
| R11 | 1 MΩ | 0.1% thin-film, ≤50 ppm/°C | **RF** (5.1 M/10 M 교체 풋프린트) |
| R12, R13 | 1 kΩ ×2 | — | SAADC 입력 RC |
| R14 | 1 kΩ | — | LED 직렬 |
| R15 | 0 Ω | 0402 | 안테나 pi 튜닝 직렬 슬롯 (C35·C34 션트와 함께 션트-직렬-션트 — 2450AT07A0100 데이터시트 요구) |
| L2, L3 | 10 µH (LQM21PN100) + 15 nH | 0805/0402 | DCC→DEC4 DC/DC 인덕터 (미사용 시 LDO 모드로 무해) |
| TH1 | NTC 10 kΩ | B≈3380 | BQ51013B TS/CTRL — LIR2032 홀더 밀착 배치 |

## 참고

- RF/CF 교체 옵션: 1 M/470 p(기본) · 5.1 M/100 p · 10 M/47 p — 펌웨어 `rf_ohm`/`oversample`은 런타임 설정.
- U4 업그레이드 옵션(핀호환): LPV812(오프셋 ±0.3 mV 정밀형) · OPA2391(fA급 Ib, 22 µA/ch — 이전 채택품).
- 충전 체인은 2단(Qi 5 V → 저전류 충전기): BQ51050B 직접충전이 TI 공식으로 <200 mA 비권장이라 교체됨 (`design.md` §5).
- 초소형화 시 동일 토폴로지로 BQ51003(DSBGA-28) + BQ25100(DSBGA-6) 교체 가능.
- MCU는 칩다운(모듈 미사용) — 의도적 방사체 무선 인증(KC/FCC/CE RED) + 안테나 튜닝 필요. 결정 근거는 `module-vs-chipdown.md`.

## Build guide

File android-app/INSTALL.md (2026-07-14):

# GLU 설치 (연결된 태블릿/폰에 바로)

앱 이름은 **GLU**. 아래는 **너의 컴퓨터**에서 실행한다 (이 저장소를 클론/풀 받은 뒤).
안드로이드 SDK 가 있는 환경이어야 컴파일된다 (안드로이드 스튜디오 설치 시 자동 포함).

## 가장 쉬운 방법 — 안드로이드 스튜디오

1. 안드로이드 스튜디오에서 **`android-app/` 폴더 열기** (File → Open)
2. 태블릿을 USB 로 연결하고 개발자 옵션 → **USB 디버깅 켜기** (태블릿에 뜨는 허용 팝업 수락)
3. 상단 기기 드롭다운에서 태블릿 선택 → **Run ▶**
   → 빌드 후 태블릿에 **GLU** 가 설치되고 실행됨

## CLI 한 줄 — adb 로 바로 설치

태블릿을 USB 로 연결(USB 디버깅 ON)한 상태에서:

```bash
cd android-app
./gradlew installDebug        # 빌드 + 연결된 기기에 GLU 설치
```

기기가 여러 대면 먼저 확인:

```bash
adb devices                    # 태블릿이 목록에 보이는지
```

설치만 따로 하려면 (이미 APK 를 뽑았을 때):

```bash
./gradlew assembleDebug
adb install -r app/build/outputs/apk/debug/app-debug.apk
```

## 처음 실행 시

- 블루투스 **스캔/연결 권한** 허용 팝업 → 수락
- 태블릿 블루투스 ON → 앱이 자동으로 **pstat** 기기를 검색 → 목록에서 탭하면 연결
- 연결되면 현재 전류·배터리·그래프가 실시간으로 갱신

## 안 될 때

- `SDK location not found` → 안드로이드 스튜디오로 한 번 열면 `local.properties` 가 자동 생성됨
  (또는 `ANDROID_HOME` 환경변수 설정)
- `adb: no devices` → USB 케이블/디버깅 승인 확인, `adb kill-server && adb start-server`
- 스캔에 기기가 안 뜸 → 태블릿 위치정보(안드로이드 11 이하)·블루투스 ON, pstat 전원 확인

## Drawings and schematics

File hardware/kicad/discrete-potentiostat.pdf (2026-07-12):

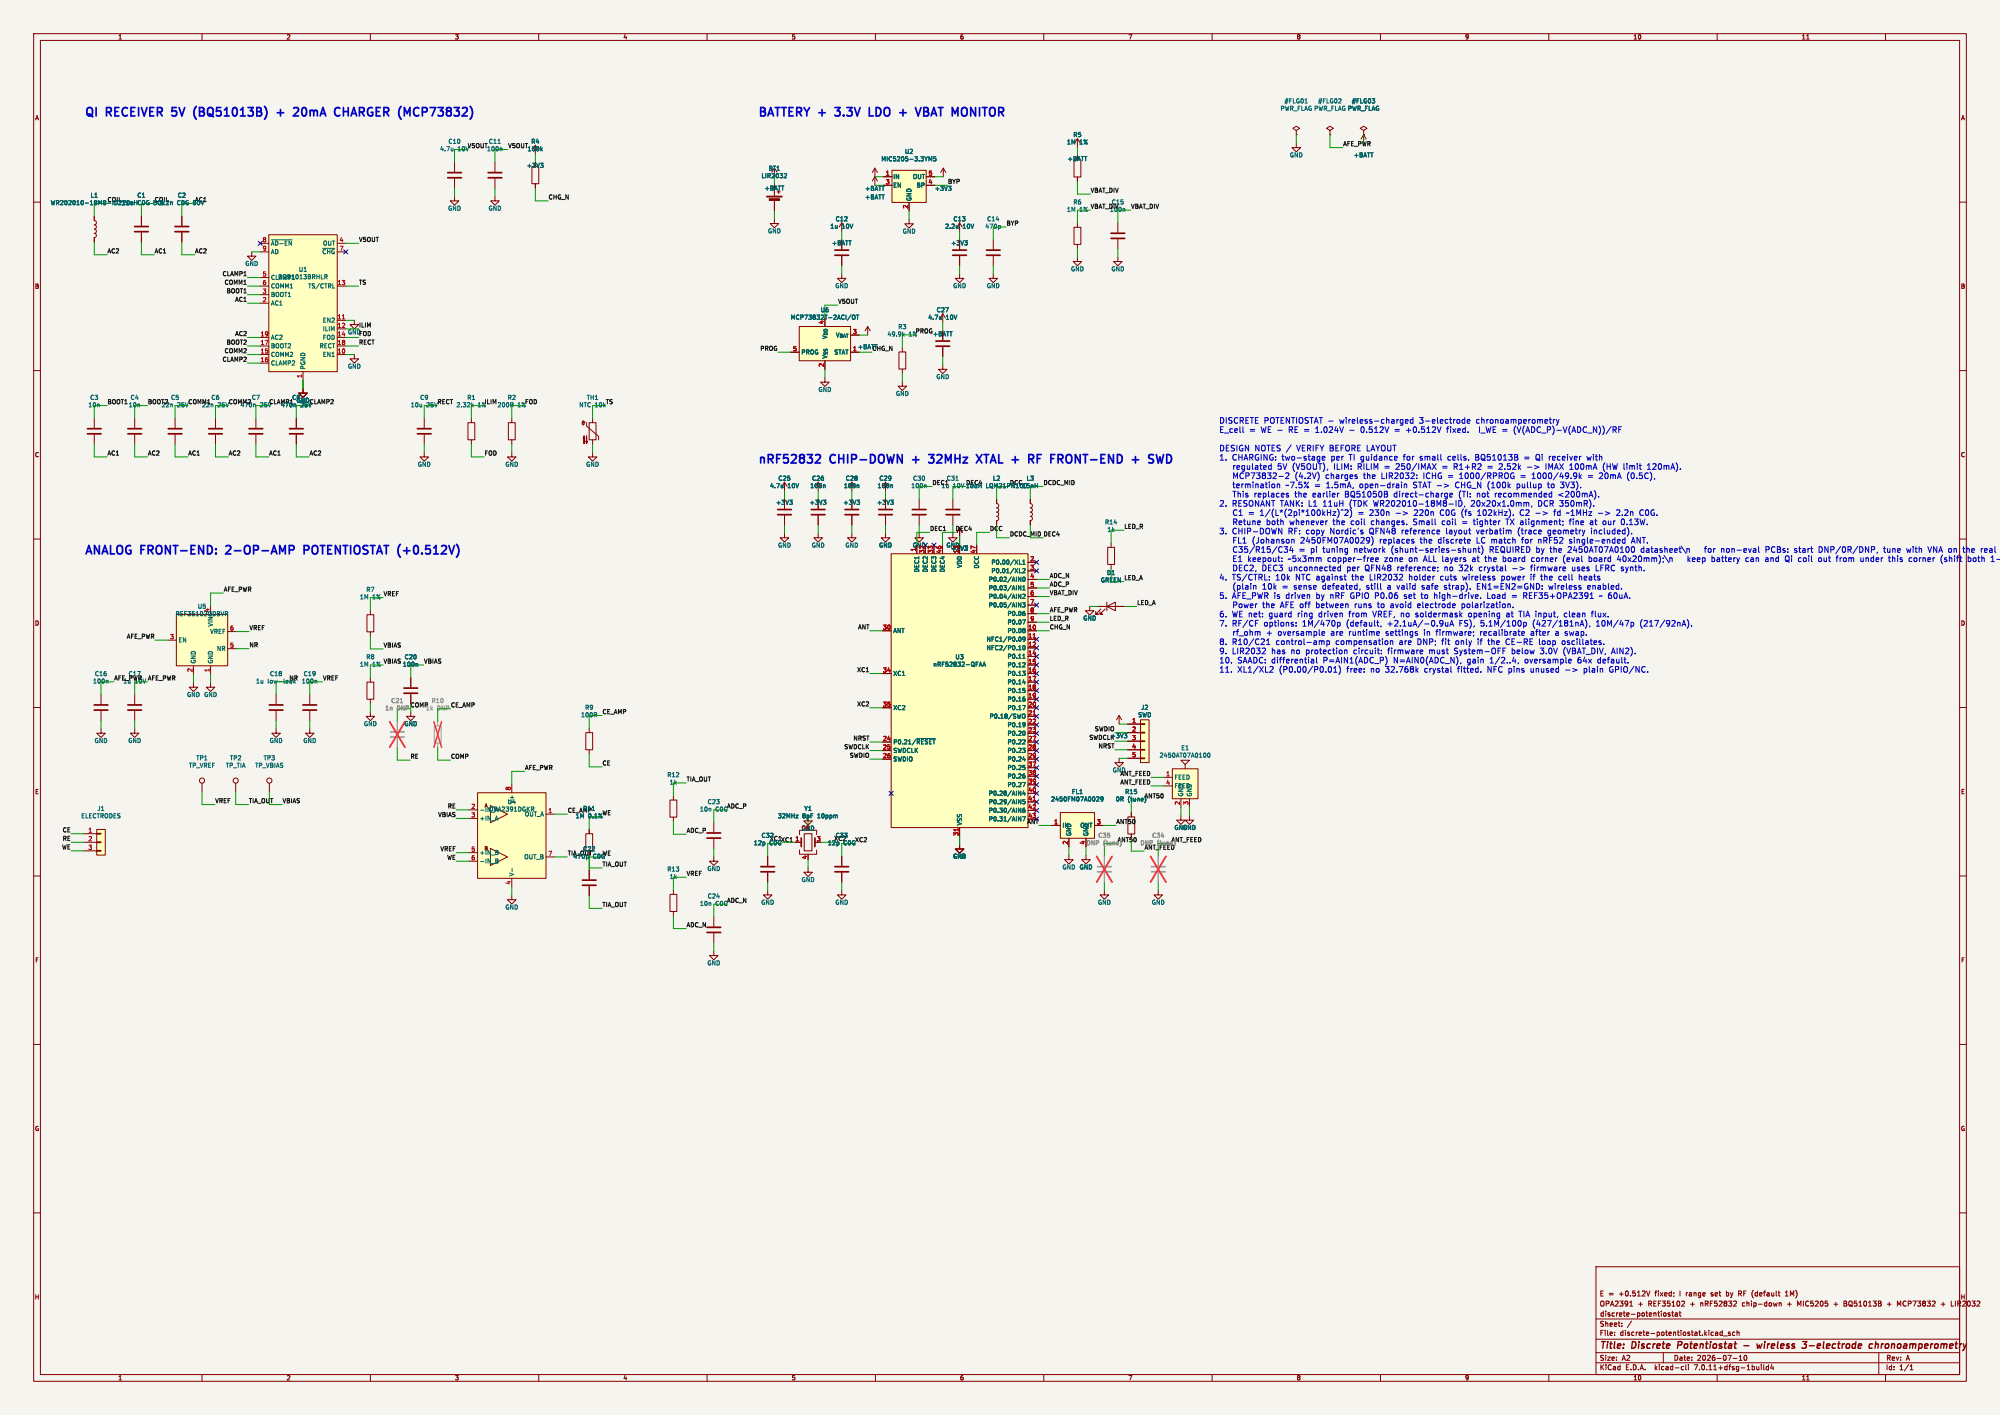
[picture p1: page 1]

2 EN 3 BP 4 OUT 5 U2 MIC5205-3.3YM5 +BATT

2 EN 3 BP 4 OUT 5 +BATT

DESIGN NOTES / VERIFY BEFORE LAYOUT
3. CHIP-DOWN RF: copy Nordic's QFN48 reference layout verbatim (trace geometry included).

1 P0.08 10 NFC1/P0.09 11 NFC2/P0.10 12 VDD 13 P0.11 14 P0.12 15 P0.13 16 P0.14 17 P0.15 18 P0.16 19 P0.00/XL1 2 P0.17 20 P0.18/SWO 21 P0.19 22 P0.20 23 P0.21/~{RESET} 24 SWDCLK 25 SWDIO 26 P0.22 27 P0.23 28 P0.24 29 P0.01/XL2 3 ANT 30 VSS 31 DEC2 32 DEC3 33 XC1 34 XC2 35 P0.25 37 P0.26 38 P0.27 39 P0.02/AIN0 4 P0.28/AIN4 40 P0.29/AIN5 41 P0.30/AIN6 42 P0.31/AIN7 43 DEC4 46 DCC 47 P0.03/AIN1 5 P0.04/AIN2 6 P0.05/AIN3 7 P0.06 8 P0.07 9 C33

1 P0.08 10 NFC1/P0.09 11 NFC2/P0.10 12 VDD 13 P0.11 14 P0.12 15 P0.13 16 P0.14 17 P0.15 18 P0.16 19 P0.00/XL1 2 P0.17 20 P0.18/SWO 21 P0.19 22 P0.20 23 P0.21/~{RESET} 24 SWDCLK 25 SWDIO 26 P0.22 27 P0.23 28 P0.24 29 P0.01/XL2 3 ANT 30 VSS 31 DEC2 32 DEC3 33 XC1 34 XC2 35 P0.25 37 P0.26 38 P0.27 39 P0.02/AIN0 4 P0.28/AIN4 40 P0.29/AIN5 41 P0.30/AIN6 42 P0.31/AIN7 43 DEC4 46 DCC 47 P0.03/AIN1 5 P0.04/AIN2 6 P0.05/AIN3 7 P0.06 8 P0.07 9 U3

4. TS/CTRL: 10k NTC against the LIR2032 holder cuts wireless power if the cell heats

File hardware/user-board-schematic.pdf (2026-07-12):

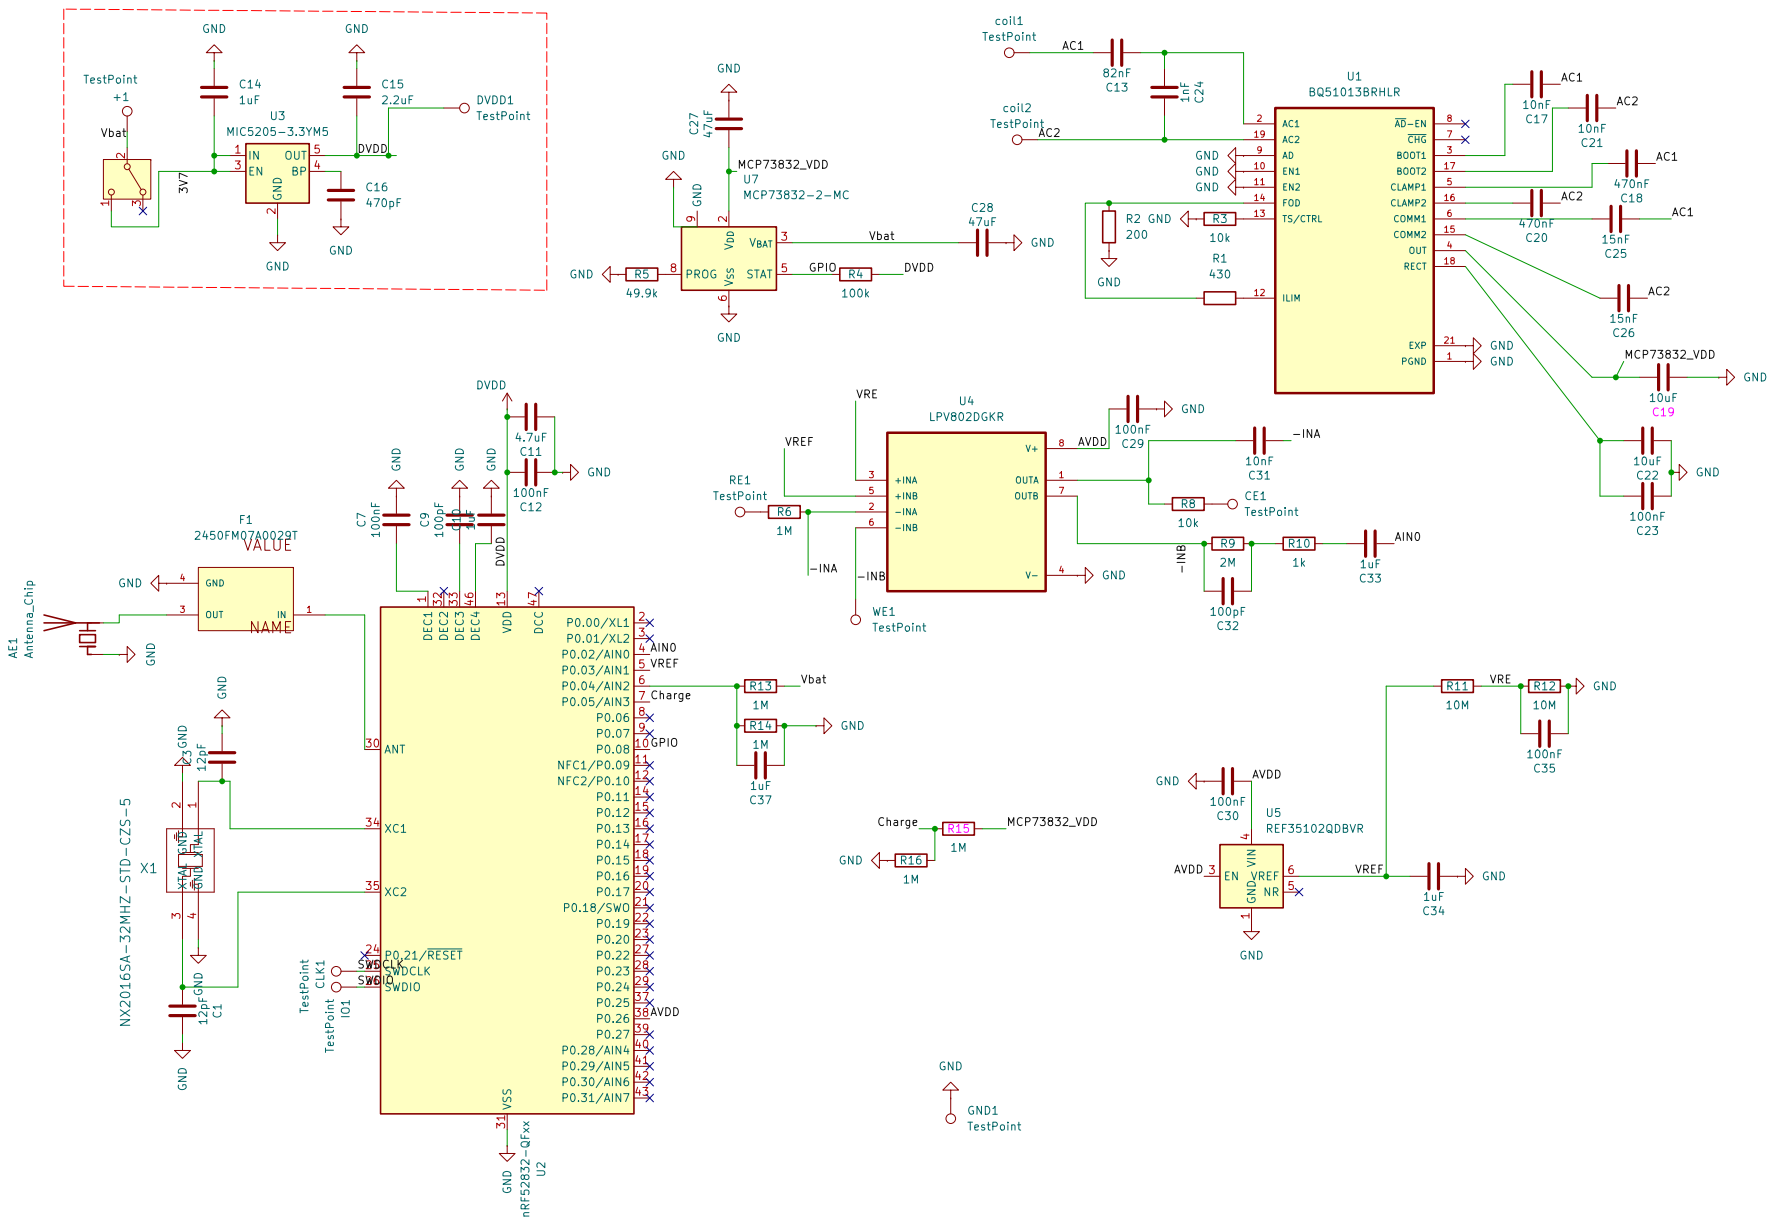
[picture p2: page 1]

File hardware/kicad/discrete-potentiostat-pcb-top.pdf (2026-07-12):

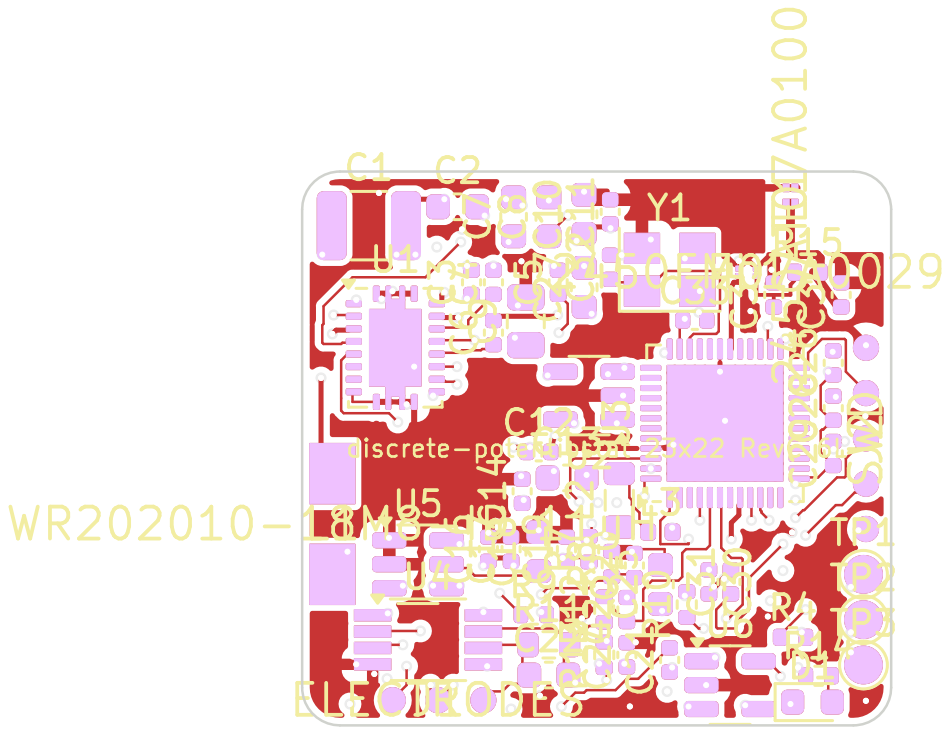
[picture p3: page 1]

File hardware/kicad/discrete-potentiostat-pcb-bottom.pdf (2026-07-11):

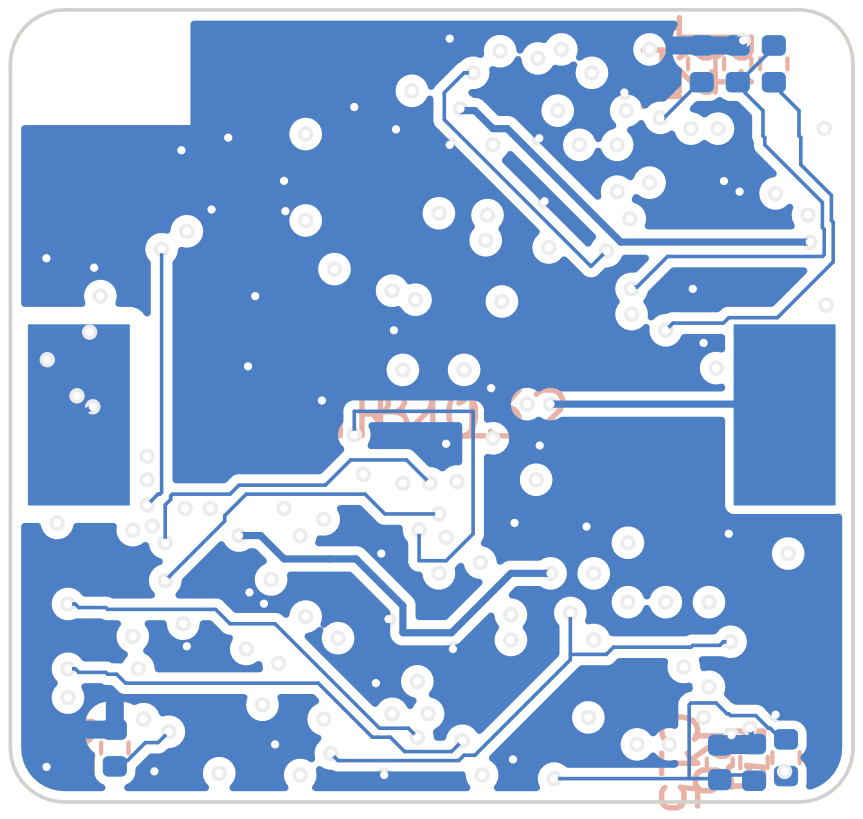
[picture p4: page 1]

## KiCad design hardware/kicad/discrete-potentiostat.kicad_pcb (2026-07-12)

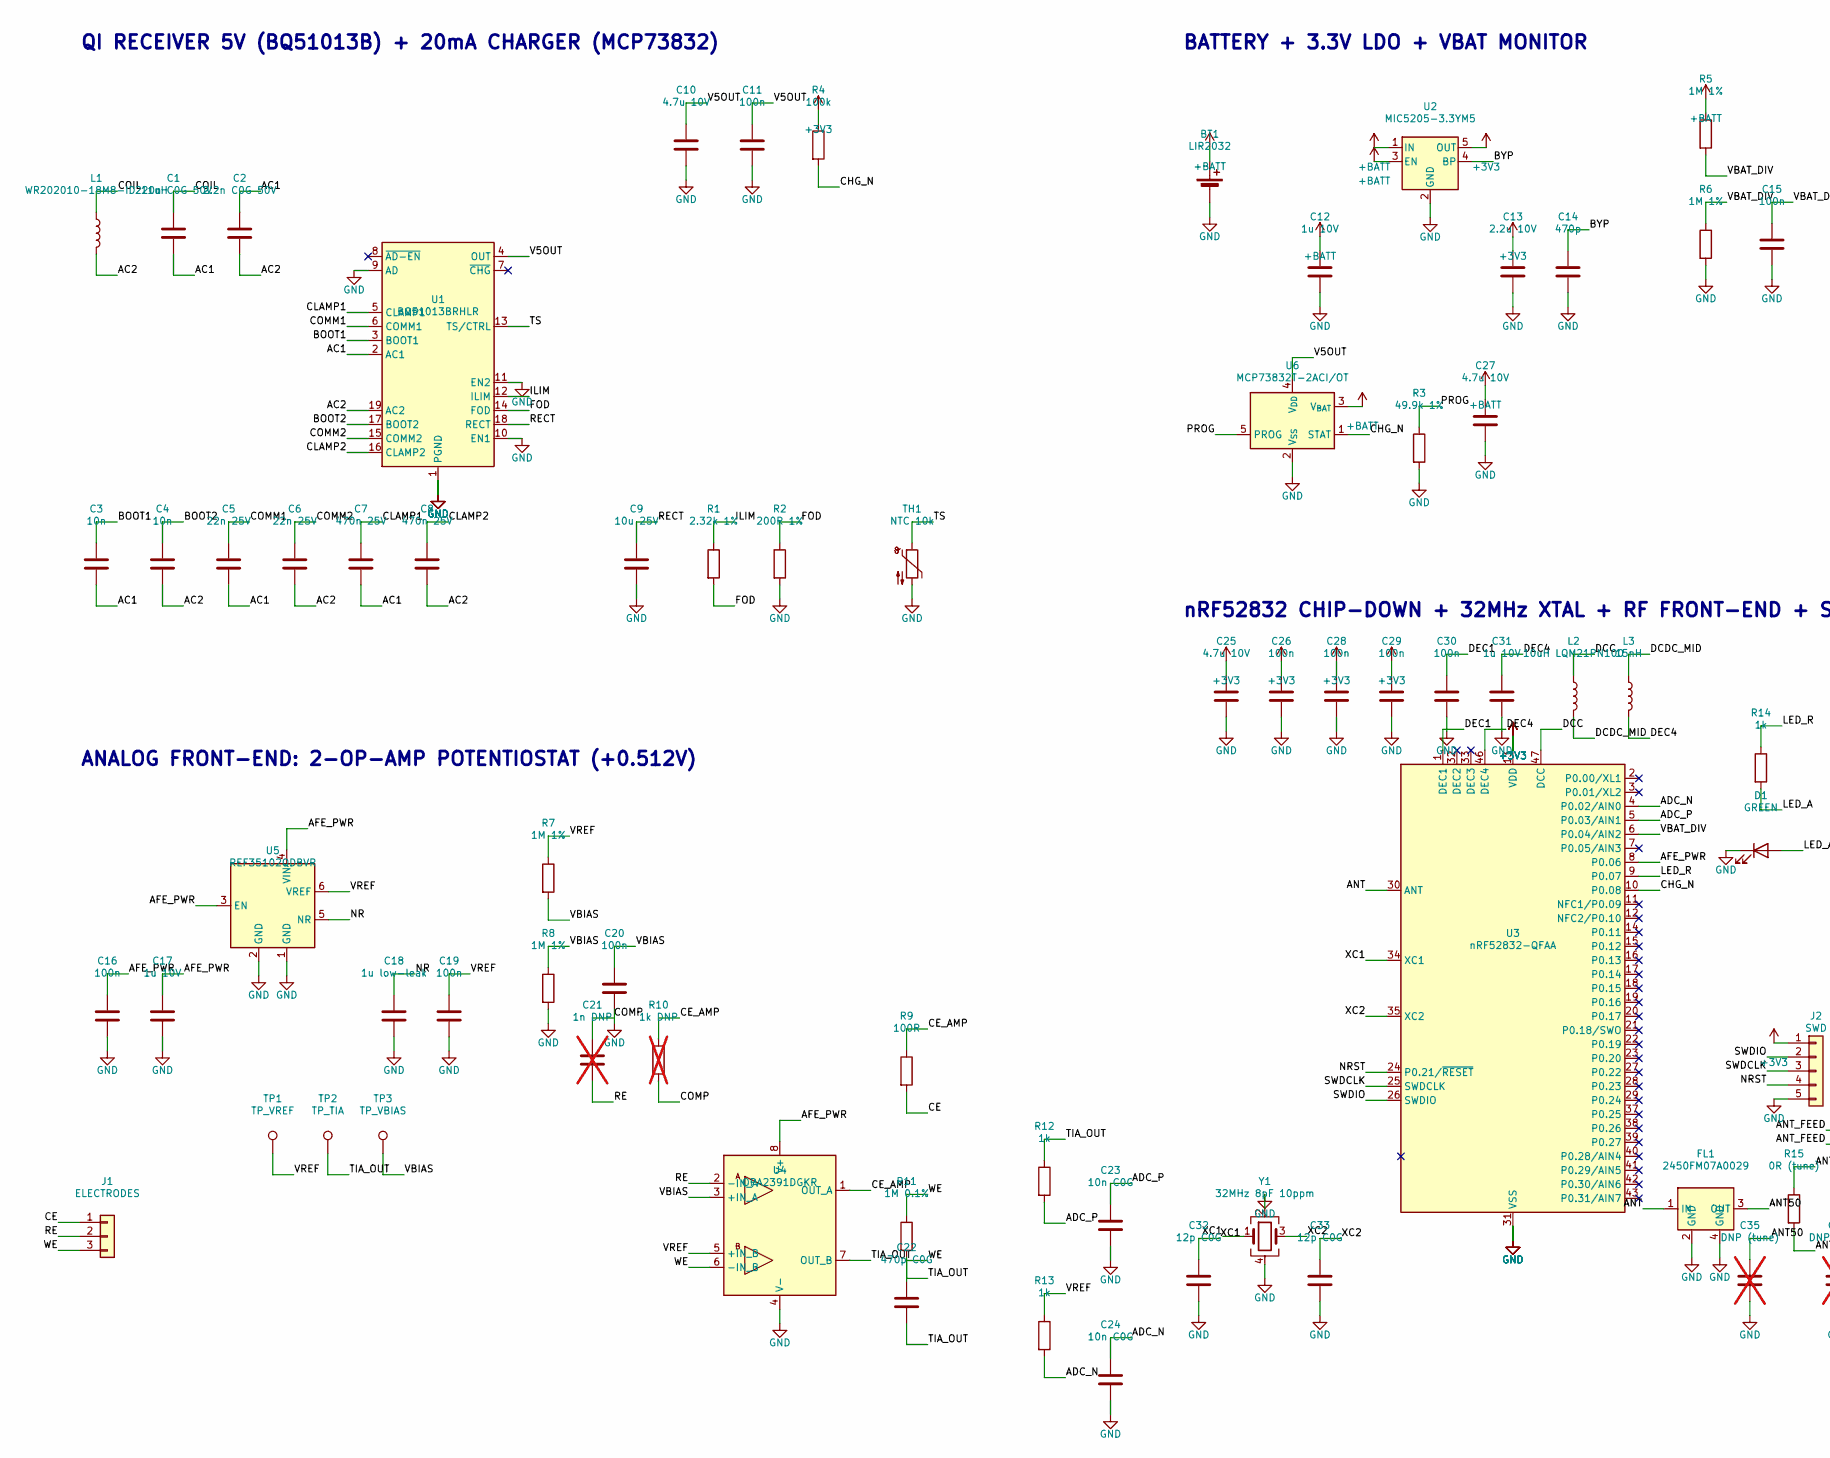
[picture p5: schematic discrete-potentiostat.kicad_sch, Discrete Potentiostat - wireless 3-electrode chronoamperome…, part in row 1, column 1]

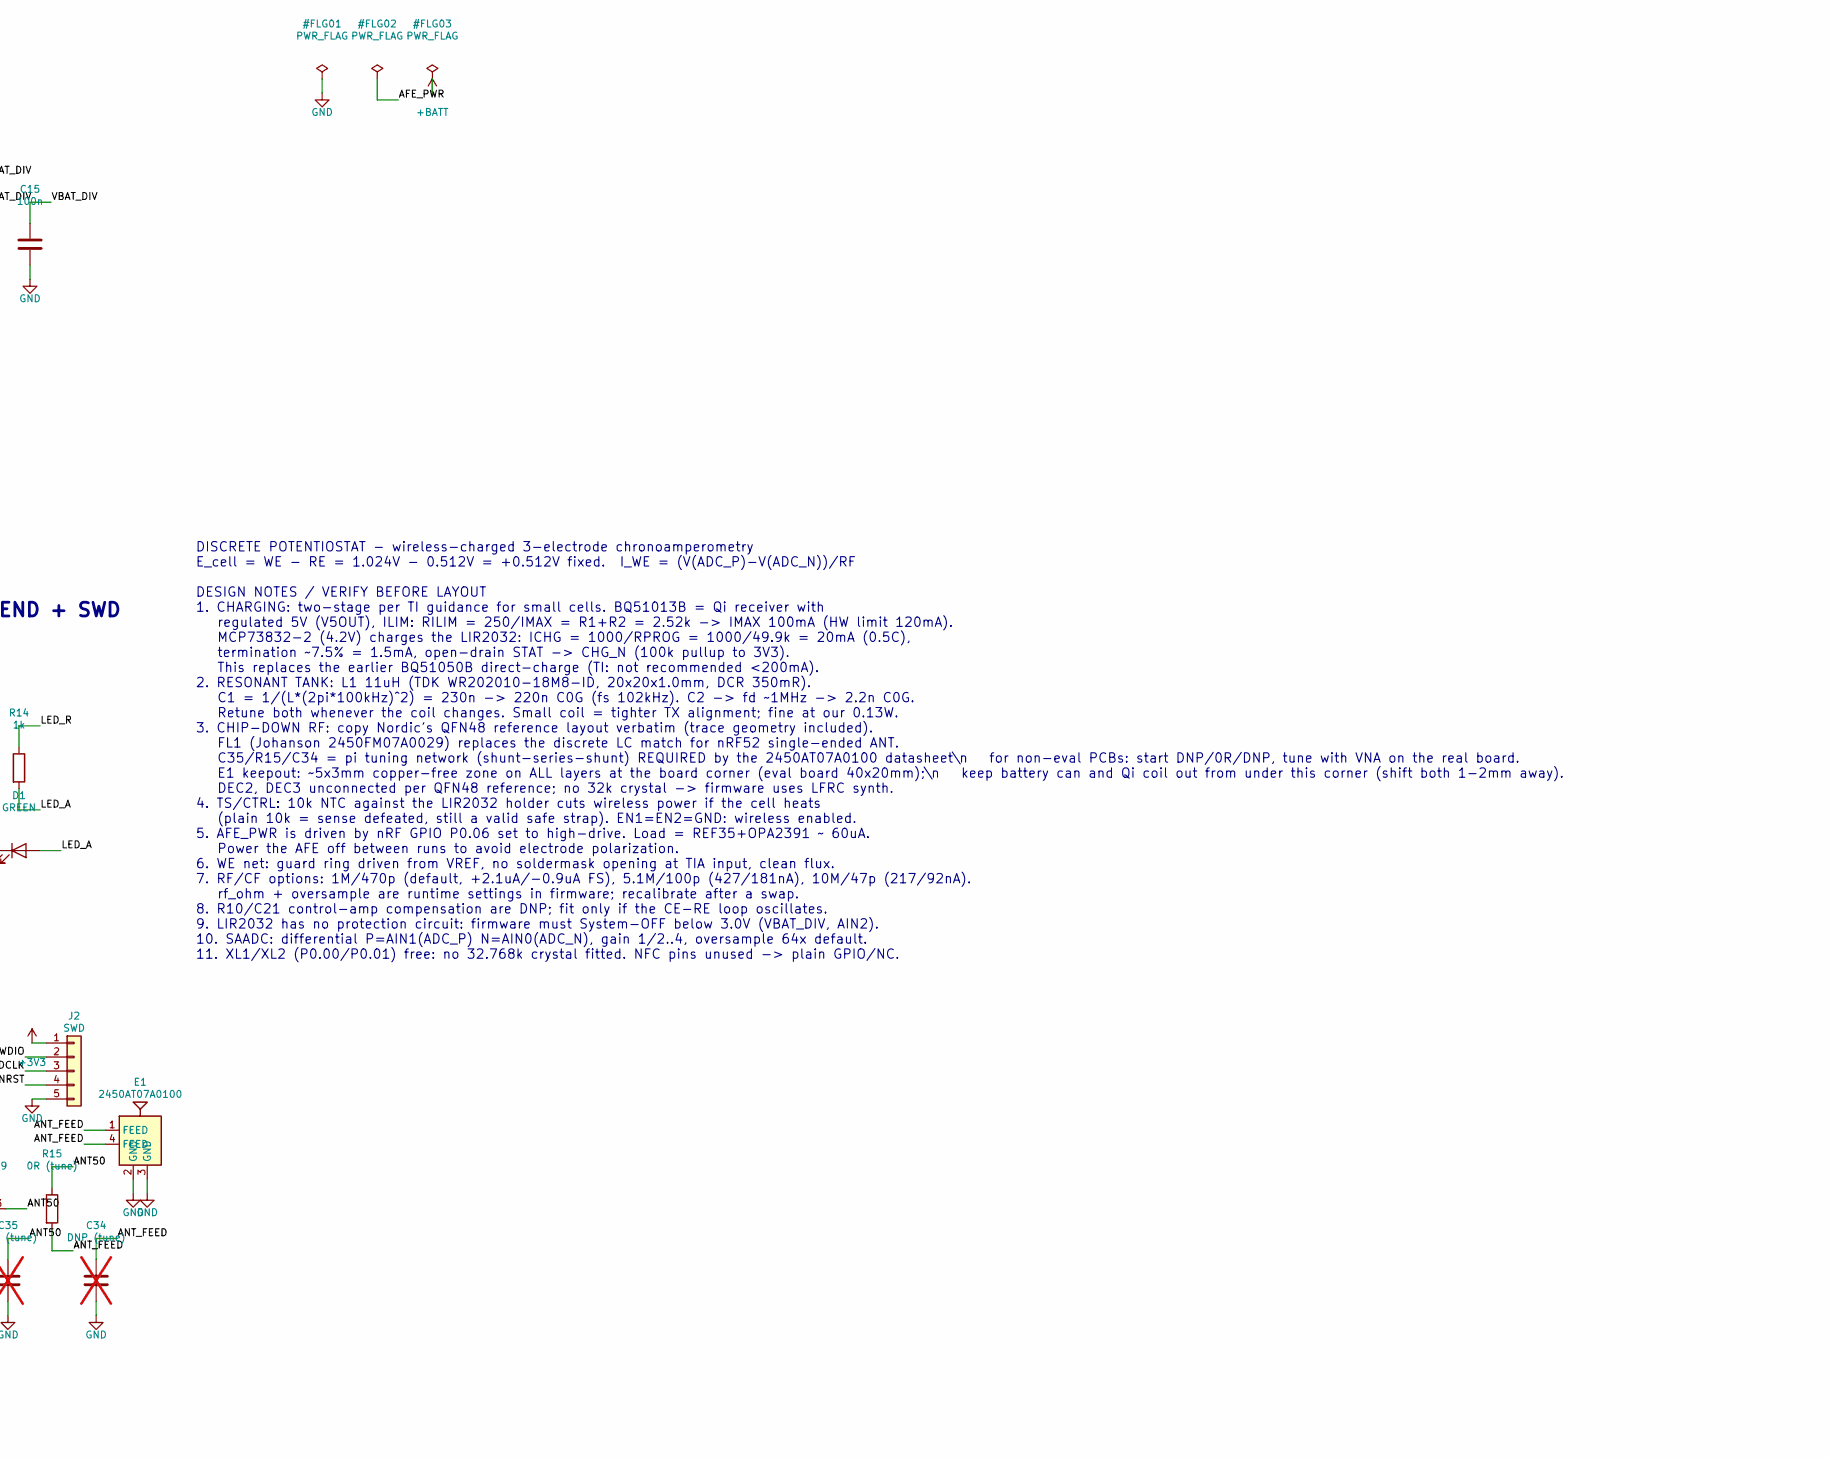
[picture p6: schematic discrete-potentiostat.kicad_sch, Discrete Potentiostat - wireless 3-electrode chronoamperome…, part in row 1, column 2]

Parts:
BT1: LIR2032; BatteryHolder_Keystone_3034_1x20mm
C1: 220n C0G 50V; C_1210_3225Metric
C2: 2.2n C0G 50V; C_0603_1608Metric
C3, C4: 10n; C_0402_1005Metric
C5, C6: 22n 25V; C_0402_1005Metric
C7, C8: 470n 25V; C_0603_1608Metric
C9: 10u 25V; C_0805_2012Metric
C10, C25, C27: 4.7u 10V; C_0603_1608Metric
C11, C15, C16, C19, C20, C26, C28, C29, C30: 100n; C_0402_1005Metric
C12, C17, C31: 1u 10V; C_0402_1005Metric
C13: 2.2u 10V; C_0603_1608Metric
C14: 470p; C_0402_1005Metric
C18: 1u low-leak; C_0603_1608Metric
C21: 1n DNP; C_0402_1005Metric; not fitted
C22: 470p C0G; C_0603_1608Metric
C23, C24: 10n C0G; C_0402_1005Metric
C32, C33: 12p C0G; C_0402_1005Metric
C34, C35: DNP (tune); C_0402_1005Metric; not fitted
D1: GREEN; LED_0603_1608Metric
E1: 2450AT07A0100; Johanson_2450AT07A0100
FL1: 2450FM07A0029; Johanson_0402_4pin
J1: ELECTRODES; SolderPads_1x03_D1.0mm
J2: SWD; SolderPads_1x05_D1.0mm
L1: WR202010-18M8-ID 11uH; TDK_WR202010
L2: 10uH LQM21PN100; L_0805_2012Metric
L3: 15nH; L_0402_1005Metric
R1: 2.32k 1%; R_0402_1005Metric
R2: 200R 1%; R_0402_1005Metric
R3: 49.9k 1%; R_0402_1005Metric
R4: 100k; R_0402_1005Metric
R5, R6, R7, R8: 1M 1%; R_0402_1005Metric
R9: 100R; R_0402_1005Metric
R10: 1k DNP; R_0402_1005Metric; not fitted
R11: 1M 0.1%; R_0603_1608Metric
R12, R13, R14: 1k; R_0402_1005Metric
R15: 0R (tune); R_0402_1005Metric
TH1: NTC 10k; R_0402_1005Metric
TP1: TP_VREF; TestPoint_Pad_D1.5mm
TP2: TP_TIA; TestPoint_Pad_D1.5mm
TP3: TP_VBIAS; TestPoint_Pad_D1.5mm
U1: BQ51013BRHLR; Texas_VQFN-RHL-20
U2: MIC5205-3.3YM5; SOT-23-5
U3: nRF52832-QFAA; QFN-48-1EP_6x6mm_P0.4mm_EP4.6x4.6mm
U4: OPA2391DGKR; VSSOP-8_3.0x3.0mm_P0.65mm
U5: REF35102QDBVR; SOT-23-6
U6: MCP73832T-2ACI/OT; SOT-23-5
Y1: 32MHz 8pF 10ppm; Crystal_SMD_3225-4Pin_3.2x2.5mm

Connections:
+3V3: C13.1, C25.1, C26.1, C28.1, C29.1, J2.1, R4.1, U2.5 (OUT), U3.13 (VDD), U3.36 (VDD), U3.48 (VDD)
+BATT: BT1.1 (+), C12.1, C27.1, R5.1, U2.1 (IN), U2.3 (EN), U6.3 (V_{BAT})
AC1: C1.2, C2.1, C3.2, C5.2, C7.2, U1.2 (AC1)
AC2: C2.2, C4.2, C6.2, C8.2, L1.2, U1.19 (AC2)
ADC_N: C24.1, R13.2, U3.4 (P0.02/AIN0)
ADC_P: C23.1, R12.2, U3.5 (P0.03/AIN1)
AFE_PWR: C16.1, C17.1, U3.8 (P0.06), U4.8 (V+), U5.3 (EN), U5.4 (VIN)
ANT: FL1.1 (IN), U3.30 (ANT)
ANT50: C35.1, FL1.3 (OUT), R15.1
ANT_FEED: C34.1, E1.1 (FEED), E1.4 (FEED), R15.2
BOOT1: C3.1, U1.3 (BOOT1)
BOOT2: C4.1, U1.17 (BOOT2)
BYP: C14.1, U2.4 (BP)
CE: J1.1, R9.2
CE_AMP: R9.1, R10.1, U4.1 (OUT_A)
CHG_N: R4.2, U3.10 (P0.08), U6.1 (STAT)
CLAMP1: C7.1, U1.5 (CLAMP1)
CLAMP2: C8.1, U1.16 (CLAMP2)
COIL: C1.1, L1.1
COMM1: C5.1, U1.6 (COMM1)
COMM2: C6.1, U1.15 (COMM2)
COMP: C21.1, R10.2
DCC: L2.1, U3.47 (DCC)
DCDC_MID: L2.2, L3.1
DEC1: C30.1, U3.1 (DEC1)
DEC4: C31.1, L3.2, U3.46 (DEC4)
FOD: R1.2, R2.1, U1.14 (FOD)
GND: BT1.2 (-), C9.2, C10.2, C11.2, C12.2, C13.2, C14.2, C15.2, C16.2, C17.2, C18.2, C19.2, C20.2, C23.2, C24.2, C25.2, C26.2, C27.2, C28.2, C29.2, C30.2, C31.2, C32.2, C33.2, C34.2, C35.2, D1.1 (K), E1.2 (GND), E1.3 (GND), FL1.2 (GND), FL1.4 (GND), J2.5, R2.2, R3.2, R6.2, R8.2, TH1.2, U1.1 (PGND), U1.9 (AD), U1.10 (EN1), U1.11 (EN2), U1.20 (PGND), U1.21 (PGND), U2.2 (GND), U3.31 (VSS), U3.45 (VSS), U3.49 (VSS), U4.4 (V-), U5.1 (GND), U5.2 (GND), U6.2 (V_{SS}), Y1.2, Y1.4
ILIM: R1.1, U1.12 (ILIM)
LED_A: D1.2 (A), R14.2
LED_R: R14.1, U3.9 (P0.07)
NR: C18.1, U5.5 (NR)
NRST: J2.4, U3.24 (P0.21/~RESET)
PROG: R3.1, U6.5 (PROG)
RE: C21.2, J1.2, U4.2 (-IN_A)
RECT: C9.1, U1.18 (RECT)
SWDCLK: J2.3, U3.25 (SWDCLK)
SWDIO: J2.2, U3.26 (SWDIO)
TIA_OUT: C22.2, R11.2, R12.1, TP2.1, U4.7 (OUT_B)
TS: TH1.1, U1.13 (TS/CTRL)
V5OUT: C10.1, C11.1, U1.4 (OUT), U6.4 (V_{DD})
VBAT_DIV: C15.1, R5.2, R6.1, U3.6 (P0.04/AIN2)
VBIAS: C20.1, R7.2, R8.1, TP3.1, U4.3 (+IN_A)
VREF: C19.1, R7.1, R13.1, TP1.1, U4.5 (+IN_B), U5.6 (VREF)
WE: C22.1, J1.3, R11.1, U4.6 (-IN_B)
XC1: C32.1, U3.34 (XC1), Y1.1
XC2: C33.1, U3.35 (XC2), Y1.3

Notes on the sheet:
DISCRETE POTENTIOSTAT - wireless-charged 3-electrode chronoamperometry E_cell = WE - RE = 1.024V - 0.512V = +0.512V fixed. I_WE = (V(ADC_P)-V(ADC_N))/RF DESIGN NOTES / VERIFY BEFORE LAYOUT 1. CHARGING: two-stage per TI guidance for small cells. BQ51013B = Qi receiver with regulated 5V (V5OUT), ILIM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
QI RECEIVER 5V (BQ51013B) + 20mA CHARGER (MCP73832)
BATTERY + 3.3V LDO + VBAT MONITOR
ANALOG FRONT-END: 2-OP-AMP POTENTIOSTAT (+0.512V)
nRF52832 CHIP-DOWN + 32MHz XTAL + RF FRONT-END + SWD

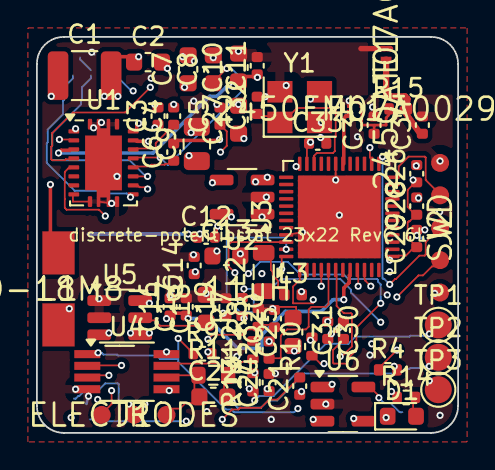
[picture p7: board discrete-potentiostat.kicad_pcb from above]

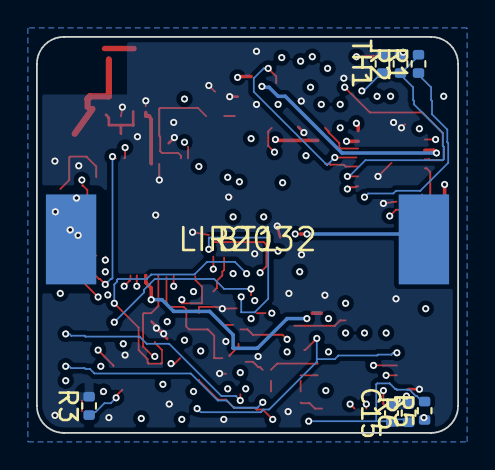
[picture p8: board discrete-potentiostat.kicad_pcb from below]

Board: 6 copper layers, 23.4 x 22.0 mm, 70 parts (8 on the bottom side), 47 nets.

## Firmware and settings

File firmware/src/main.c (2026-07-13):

/*
 * ============================================================
 *  디스크리트 크로노암페로메트리 포텐쇼스탯 — 앱 제어형
 *  (nRF52832 SAADC 직접측정 — AD5941 없음)
 *  ------------------------------------------------------------
 *  - 전위 +0.512V 하드웨어 고정 (REF35102 1.024V + 1:1 분압)
 *  - LPV802 TIA (RF 교체가능: 1M/5.1M/10M) → SAADC 차동 (AIN0−AIN1)
 *  - SAADC 게인 오토레인지 {4, 1, 1/2} + 히스테리시스 + settle 폐기
 *  - HW 오버샘플링(런타임 설정) + 시간기반 페이싱 소프트 평균
 *  - 실행모드: Continuous / Timed / Cycle (대기중 AFE 전원 off = 분극 방지)
 *  - BLE NUS: JSON 명령(start/stop/config/ack/status/zero/cal),
 *    무손실 스트림 {"d":[[seq,t_ms,nA,range],...]} — AD5941 버전과 포맷 동일
 *  - 측정 파라미터 앱 제어: rate/mode/auto/range + rf/os (NVM 저장)
 *  - 캘리브레이션: zero(게인별 오프셋) / cal(더미셀 스케일) — NVM 저장
 *  - 배터리: VBAT 분압 감시, <3.3V 경고+start 거부, <3.0V System OFF
 *
 *  구조: meas_thread = AFE 전원+SAADC 측정 -> databuf 적재
 *        main loop   = databuf -> BLE 전송(무손실) + 상태/배터리 보고
 *        nus_received= JSON 명령 파싱 -> 상태머신/ACK/캘리브레이션 신호
 * ============================================================
 */

#include <zephyr/kernel.h>
#include <zephyr/sys/util.h>
#include <zephyr/sys/atomic.h>
#include <zephyr/sys/poweroff.h>
#include <zephyr/logging/log.h>

#include <zephyr/bluetooth/bluetooth.h>
#include <zephyr/bluetooth/conn.h>
#include <zephyr/bluetooth/gatt.h>
#include <bluetooth/services/nus.h>

#include "pstat.h"
#include "meas.h"
#include "store.h"
#include "databuf.h"
#include "flog.h"
#include "cmd.h"

LOG_MODULE_REGISTER(pstat, LOG_LEVEL_INF);

/* ===================== 고정 상수 ===================== */
#define BIAS_MV        512.0f   /* 인가 전위 V(WE)-V(RE) = +0.512V (하드웨어 고정) */
#define AFE_SETTLE_MS  50       /* AFE_PWR on -> REF/앰프/RC 안정화 대기 */

/* 오토레인지 임계 (|ΔV| / FS 비율) — 게인비 4×/2× 에서 진동 없는 값 */
#define SAT_HI_FRAC    0.85f    /* 초과 시 게인 다운 (범위↑) */
#define SAT_LO_FRAC    0.18f    /* 미만 시 게인 업 (감도↑) */
#define AR_SETTLE      4        /* 게인 변경 후 '결정' 억제 샘플 수 */
#define RANGE_FLUSH    1        /* 게인 변경 직후 버릴 변환 수 */

/* 배터리 정책 (LIR2032 무보호 셀 — 펌웨어가 과방전 보호) */
#define VBAT_WARN_MV   3300     /* 경고 + 신규 start 거부 */
#define VBAT_CUT_MV    3000     /* 데이터 플러시 후 System OFF */
#define VBAT_PERIOD_MS 600000   /* 10분 */

/* BLE 연결간격 (1.25ms 단위), supervision timeout (10ms 단위)
 * — AD5941 버전에서 검증된 상시 빠른 간격 유지 (전환 지연/타임아웃 회피) */
#define CONN_FAST_MIN  24       /* 30ms */
#define CONN_FAST_MAX  40       /* 50ms */
#define CONN_REST_MIN  24
#define CONN_REST_MAX  40
#define CONN_TIMEOUT   500      /* 5000ms (iOS: interval*3 < timeout) */

/* ===================== 상태 ===================== */
static atomic_t g_state = ATOMIC_INIT(PSTAT_IDLE);
static volatile bool stop_req;
static K_SEM_DEFINE(start_sem, 0, 1);

static struct pstat_config g_cfg = {  /* 기본값 (rf/os 는 NVM 이 덮음) */
	.rate_hz = 10, .mode = PSTAT_MODE_CONTINUOUS, .autorange = true,
	.range_idx = 0, .duration_s = 60, .on_s = 5, .off_s = 295, .cycles = 0,
	.rf_ohm = 2000000, .oversample = 64,
};
static struct pstat_cal g_cal = { .scale = 1.0f, .off_nA = { 0 } };
static K_MUTEX_DEFINE(cfg_lock);

static struct pstat_config rc;   /* run copy (run() 진입 시 스냅샷) */
static int      cur_range;       /* 현재 게인 인덱스 (0=최고감도) */
static int      ar_settle;       /* 오토레인지 결정 억제 카운터 */
static int      range_flush;     /* 게인 변경 후 버릴 변환 수 */
static uint32_t run_t0;
static uint32_t run_cycle;
static uint32_t next_due;        /* 시간기반 페이싱: 다음 출력샘플 마감 */
static volatile bool status_req;
static volatile uint8_t cal_req;      /* 0=없음 1=zero 2=scale */
static volatile uint32_t cal_kohm;
static int      g_vbat_mv = -1;       /* 최근 배터리 전압 (main loop 갱신) */
static bool     low_batt;             /* <VBAT_WARN_MV */

/* ===================== BLE 전방선언 ===================== */
static struct bt_conn *current_conn;
static K_MUTEX_DEFINE(conn_lock);
static volatile bool notif_enabled;
static void ble_set_fast(bool fast);
static int tx_nus(const uint8_t *data, uint16_t len);

static struct bt_conn *conn_get(void)
{
	struct bt_conn *c = NULL;
	k_mutex_lock(&conn_lock, K_FOREVER);
	if (current_conn) {
		c = bt_conn_ref(current_conn);
	}
	k_mutex_unlock(&conn_lock);
	return c;
}

/* ===================== 측정 코어 (SAADC) ===================== */

/* ΔV[V] -> 전류[nA] (RF/캘리브레이션 반영) */
static float dv_to_nA(float dv)
{
	float raw = (dv / (float)rc.rf_ohm) * 1e9f;
	return raw * g_cal.scale - g_cal.off_nA[cur_range];
}

static void apply_range(int idx)
{
	if (meas_set_gain(idx) == 0) {
		cur_range = idx;
		ar_settle = AR_SETTLE;
		range_flush = RANGE_FLUSH;
	}
}

static void autorange_update(float dv)
{
	if (ar_settle > 0) {
		ar_settle--;
		return;
	}
	float av = (dv < 0) ? -dv : dv;
	float fs = meas_fs_volts();
	if (av > SAT_HI_FRAC * fs && cur_range < GAIN_N - 1) {
		apply_range(cur_range + 1);   /* 감도↓ 범위↑ */
	} else if (av < SAT_LO_FRAC * fs && cur_range > 0) {
		apply_range(cur_range - 1);   /* 감도↑ */
	}
}

/* AFE 전원 on + 초기 게인 + 안정화 */
static void afe_start(int range_idx)
{
	afe_power(true);
	k_msleep(AFE_SETTLE_MS);
	cur_range = -1;               /* meas_set_gain 강제 적용 */
	apply_range(range_idx);
	/* 파이프라인/RC 안정화: 첫 변환 몇 개 폐기 */
	float dv;
	for (int i = 0; i < 3 && !stop_req; i++) {
		meas_read_dv(rc.oversample, &dv);
	}
	range_flush = 0;
}

static void afe_stop(void)
{
	afe_power(false);   /* 소모 0 + CE 구동 차단 → 전극 분극 방지 */
}

/* 한 출력샘플: next_due 까지 도착한 HW 오버샘플 변환을 전부 평균해
 * 정확히 rate_hz 로 출력 (AD5941 버전의 SINC2 페이싱과 동일 구조) */
static bool sample_once(struct pstat_sample *smp)
{
	uint32_t period_ms = 1000U / rc.rate_hz;
	float vsum = 0.0f;
	int cnt = 0;
	float dv = 0.0f;

	while (range_flush > 0) {     /* 게인 세틀 구간 폐기 */
		if (stop_req || meas_read_dv(rc.oversample, &dv) != 0) {
			return false;
		}
		range_flush--;
	}

	do {
		if (stop_req) {
			return false;
		}
		if (meas_read_dv(rc.oversample, &dv) != 0) {
			return false;
		}
		vsum += dv;
		cnt++;
	} while ((int32_t)(k_uptime_get_32() - next_due) < 0);

	next_due += period_ms;
	if ((int32_t)(k_uptime_get_32() - next_due) > (int32_t)period_ms) {
		next_due = k_uptime_get_32() + period_ms;   /* 밀림 재동기화 */
	}

	float vavg = vsum / (float)cnt;
	smp->current_nA = dv_to_nA(vavg);
	smp->t_ms       = k_uptime_get_32() - run_t0;
	smp->range_idx  = (uint8_t)cur_range;
	if (rc.autorange) {
		autorange_update(vavg);
	}
	return true;
}

static void measure_phase(uint32_t dur_ms)
{
	uint32_t t0 = k_uptime_get_32();
	struct pstat_sample smp;

	/* 요약(agg) 모드: raw 를 버리고 측정구간당 1샘플만 남긴다.
	 * Q(t)=∫I·dt (사다리꼴) 를 구간 후반 50% 에서 선형회귀 →
	 * 기울기 = 노이즈에 견고한 정상상태 전류 [nA] (끝값의 강건 버전).
	 * 구간 길이를 알아야 하므로 CYCLE/TIMED 전용 (dur_ms=0 이면 raw). */
	bool agg = rc.agg && dur_ms;
	float  q = 0.0f, prev_i = 0.0f;
	uint32_t prev_t = 0;
	bool   have_prev = false;
	double st = 0, st2 = 0, sq = 0, stq = 0;
	uint32_t n = 0;
	uint32_t phase0 = t0 - run_t0;        /* smp.t_ms 기준 구간 시작 */
	uint32_t fit_from = dur_ms / 2;       /* 후반 50% 만 피팅 (과도응답 제외) */

	next_due = t0 + 1000U / rc.rate_hz;

	while (!stop_req) {
		if (dur_ms && (k_uptime_get_32() - t0) >= dur_ms) {
			break;
		}
		if (!sample_once(&smp)) {
			break;
		}
		if (!agg) {
			databuf_push(&smp);
			continue;
		}
		if (have_prev) {
			q += 0.5f * (smp.current_nA + prev_i) *
			     (float)(smp.t_ms - prev_t) * 1e-3f;   /* [nA·s] */
		}
		prev_i = smp.current_nA;
		prev_t = smp.t_ms;
		have_prev = true;

		uint32_t ph_ms = smp.t_ms - phase0;
		if (ph_ms >= fit_from) {
			double ts = (double)(ph_ms - fit_from) * 1e-3;
			st  += ts;
			st2 += ts * ts;
			sq  += q;
			stq += ts * q;
			n++;
		}
	}

	if (agg && n >= 2) {
		double den = (double)n * st2 - st * st;
		/* 회귀 불능(구간 극단·중단)이면 마지막 전류로 폴백 */
		smp.current_nA = (den > 1e-12) ?
			(float)(((double)n * stq - st * sq) / den) : prev_i;
		smp.t_ms = k_uptime_get_32() - run_t0;
		/* smp.range_idx = 마지막 게인 그대로 */
		databuf_push(&smp);
	}
}

static void rest_delay(uint32_t ms)
{
	uint32_t t0 = k_uptime_get_32();
	while (!stop_req && (k_uptime_get_32() - t0) < ms) {
		k_msleep(50);
	}
}

static void run_once(void)
{
	int start_idx = rc.autorange ? 0 : CLAMP(rc.range_idx, 0, GAIN_N - 1);

	databuf_reset();
	run_t0 = k_uptime_get_32();
	run_cycle = 0;
	ble_set_fast(true);
	atomic_set(&g_state, PSTAT_RUN);
	status_req = true;
	led_set(true);

	if (rc.mode == PSTAT_MODE_CONTINUOUS) {
		afe_start(start_idx);
		measure_phase(0);
		afe_stop();
	} else if (rc.mode == PSTAT_MODE_TIMED) {
		afe_start(start_idx);
		measure_phase(rc.duration_s * 1000U);
		afe_stop();
	} else { /* CYCLE */
		int idx = start_idx;
		while (!stop_req) {
			run_cycle++;
			atomic_set(&g_state, PSTAT_RUN);
			ble_set_fast(true);
			led_set(true);
			/* 웜업(settle+프라이밍)을 on_s 에 포함 → 주기 길이 정확 */
			uint32_t t_on0 = k_uptime_get_32();
			afe_start(idx);
			uint32_t warm = k_uptime_get_32() - t_on0;
			uint32_t on_ms = rc.on_s * 1000U;
			measure_phase(on_ms > warm ? on_ms - warm : 1);
			afe_stop();
			if (rc.autorange) {
				idx = cur_range;   /* 수렴 게인을 다음 주기로 유지 */
			}
			if (stop_req) {
				break;
			}
			if (rc.cycles && run_cycle >= rc.cycles) {
				break;
			}
			atomic_set(&g_state, PSTAT_CYCLE_REST);
			status_req = true;
			ble_set_fast(false);
			led_set(false);
			rest_delay(rc.off_s * 1000U);
		}
	}

	atomic_set(&g_state, PSTAT_IDLE);
	status_req = true;
	ble_set_fast(false);
	led_set(false);
	LOG_INF("run finished (cycles=%u)", run_cycle);
}

/* ===================== 캘리브레이션 ===================== */

/* 게인별로 N 회 평균 ΔV[V] (AFE 는 이미 on 상태 가정) */
static float avg_dv(int gain_idx, int n)
{
	apply_range(gain_idx);
	float dv, sum = 0.0f;
	int k = 0;
	for (int i = 0; i < RANGE_FLUSH + 2; i++) {
		meas_read_dv(rc.oversample, &dv);   /* settle 폐기 */
	}
	range_flush = 0;
	for (int i = 0; i < n; i++) {
		if (meas_read_dv(rc.oversample, &dv) == 0) {
			sum += dv;
			k++;
		}
	}
	return k ? (sum / (float)k) : 0.0f;
}

/* zero: 셀 오픈(전극 미연결) 상태에서 게인별 오프셋 저장.
 * cal:  기지저항 R[kΩ] 더미셀 → 기대 I = 512mV/R, scale = 기대/측정 */
static void do_calibration(uint8_t kind, uint32_t kohm)
{
	char line[96];
	int n;

	k_mutex_lock(&cfg_lock, K_FOREVER);
	rc = g_cfg;   /* 최신 rf/os 반영 */
	k_mutex_unlock(&cfg_lock);

	afe_power(true);
	k_msleep(AFE_SETTLE_MS * 2);

	if (kind == 1) {          /* zero */
		for (int g = 0; g < GAIN_N; g++) {
			float dv = avg_dv(g, 64);
			g_cal.off_nA[g] = (dv / (float)rc.rf_ohm) * 1e9f * g_cal.scale;
		}
		store_save_cal(&g_cal);
		n = snprintk(line, sizeof(line),
			"{\"cal\":\"zero\",\"off\":[%.3f,%.3f,%.3f]}\n",
			(double)g_cal.off_nA[0], (double)g_cal.off_nA[1],
			(double)g_cal.off_nA[2]);
		tx_nus(line, n);
	} else {                  /* scale (기지저항) */
		float i_exp = (BIAS_MV * 1e6f) / ((float)kohm * 1000.0f); /* nA */
		float dv_exp = i_exp * (float)rc.rf_ohm / 1e9f;           /* V */
		/* 기대 ΔV 가 FS 의 60% 이내인 최고감도 게인 자동 선택 */
		static const float fs_v[GAIN_N] = { 0.15f, 0.6f, 1.2f };
		int g = GAIN_N - 1;
		for (int i = 0; i < GAIN_N; i++) {
			if (dv_exp < 0.6f * fs_v[i]) {
				g = i;
				break;
			}
		}
		float dv = avg_dv(g, 64);
		float i_raw = (dv / (float)rc.rf_ohm) * 1e9f - g_cal.off_nA[g] / g_cal.scale;
		if (i_raw > 0.01f) {
			g_cal.scale = i_exp / i_raw;
			g_cal.scale = CLAMP(g_cal.scale, 0.5f, 2.0f);
			store_save_cal(&g_cal);
		}
		n = snprintk(line, sizeof(line),
			"{\"cal\":\"scale\",\"exp_nA\":%.1f,\"meas_nA\":%.1f,\"scale\":%.4f}\n",
			(double)i_exp, (double)i_raw, (double)g_cal.scale);
		tx_nus(line, n);
	}

	afe_power(false);
	LOG_INF("calibration done (kind=%u)", kind);
}

/* ===================== 측정 스레드 ===================== */
static void meas_thread(void)
{
	while (1) {
		k_sem_take(&start_sem, K_FOREVER);

		if (cal_req) {                       /* 캘리브레이션 요청 */
			uint8_t kind = cal_req;
			cal_req = 0;
			do_calibration(kind, cal_kohm);
			atomic_set(&g_state, PSTAT_IDLE);
			status_req = true;
			continue;
		}

		k_mutex_lock(&cfg_lock, K_FOREVER);
		rc = g_cfg;   /* 스냅샷 */
		k_mutex_unlock(&cfg_lock);
		if (rc.rate_hz == 0) {
			rc.rate_hz = 1;
		}
		if (rc.oversample == 0) {
			rc.oversample = 1;
		}
		LOG_INF("START mode=%u rate=%uHz auto=%d rf=%u os=%u dur=%us on=%us off=%us cyc=%u",
			rc.mode, rc.rate_hz, (int)rc.autorange, rc.rf_ohm,
			rc.oversample, rc.duration_s, rc.on_s, rc.off_s, rc.cycles);
		run_once();
	}
}
K_THREAD_DEFINE(meas_tid, 3072, meas_thread, NULL, NULL, NULL, 5, 0, 0);

/* ===================== BLE ===================== */
#define DEVICE_NAME     CONFIG_BT_DEVICE_NAME
#define DEVICE_NAME_LEN (sizeof(DEVICE_NAME) - 1)

static const struct bt_data ad[] = {
	BT_DATA_BYTES(BT_DATA_FLAGS, (BT_LE_AD_GENERAL | BT_LE_AD_NO_BREDR)),
	BT_DATA(BT_DATA_NAME_COMPLETE, DEVICE_NAME, DEVICE_NAME_LEN),
};
static const struct bt_data sd[] = {
	BT_DATA_BYTES(BT_DATA_UUID128_ALL, BT_UUID_NUS_VAL),
};

static void start_advertising(void)
{
	int err = bt_le_adv_start(BT_LE_ADV_CONN_FAST_1, ad, ARRAY_SIZE(ad),
				  sd, ARRAY_SIZE(sd));
	if (err) {
		LOG_ERR("adv start failed (%d)", err);
	} else {
		LOG_INF("Advertising as '%s'", DEVICE_NAME);
	}
}
static void adv_work_handler(struct k_work *work) { start_advertising(); }
static K_WORK_DEFINE(adv_work, adv_work_handler);

static void ble_set_fast(bool fast)
{
	struct bt_conn *c = conn_get();
	if (!c) {
		return;
	}
	int err = fast
		? bt_conn_le_param_update(c, BT_LE_CONN_PARAM(CONN_FAST_MIN, CONN_FAST_MAX, 0, CONN_TIMEOUT))
		: bt_conn_le_param_update(c, BT_LE_CONN_PARAM(CONN_REST_MIN, CONN_REST_MAX, 0, CONN_TIMEOUT));
	if (err) {
		LOG_WRN("conn param update (%s) req failed (%d)", fast ? "fast" : "rest", err);
	}
	bt_conn_unref(c);
}

static void mtu_exchange_cb(struct bt_conn *conn, uint8_t err,
			    struct bt_gatt_exchange_params *params)
{
	LOG_INF("MTU exchange %s -> %u", err ? "FAIL" : "OK", bt_gatt_get_mtu(conn));
}
static struct bt_gatt_exchange_params mtu_exchange_params;

static void connected(struct bt_conn *conn, uint8_t err)
{
	if (err) {
		LOG_ERR("Connection failed (err %u)", err);
		k_work_submit(&adv_work);
		return;
	}
	k_mutex_lock(&conn_lock, K_FOREVER);
	current_conn = bt_conn_ref(conn);
	k_mutex_unlock(&conn_lock);
	notif_enabled = false;
	LOG_INF("Connected (MTU=%u)", bt_gatt_get_mtu(conn));

	mtu_exchange_params.func = mtu_exchange_cb;
	bt_gatt_exchange_mtu(conn, &mtu_exchange_params);

	databuf_rewind_unsent();
	ble_set_fast(atomic_get(&g_state) == PSTAT_RUN);
}

static void disconnected(struct bt_conn *conn, uint8_t reason)
{
	LOG_INF("Disconnected (reason %u) — 측정 계속, 버퍼 누적", reason);
	notif_enabled = false;
	k_mutex_lock(&conn_lock, K_FOREVER);
	if (current_conn) {
		bt_conn_unref(current_conn);
		current_conn = NULL;
	}
	k_mutex_unlock(&conn_lock);
	k_work_submit(&adv_work);
}

BT_CONN_CB_DEFINE(conn_callbacks) = {
	.connected = connected,
	.disconnected = disconnected,
};

static void nus_received(struct bt_conn *conn, const uint8_t *data, uint16_t len)
{
	struct cmd c;
	struct pstat_config base;

	k_mutex_lock(&cfg_lock, K_FOREVER);
	base = g_cfg;
	k_mutex_unlock(&cfg_lock);

	if (!cmd_parse((const char *)data, len, &c, &base)) {
		LOG_WRN("cmd parse fail (%u B)", len);
		return;
	}

	switch (c.type) {
	case CMD_ACK:
		/* 플래시 백로그 재생중엔 ack 가 그 배치를 가리킴 — 해제는
		 * 메인루프가 수행 (플래시 접근은 메인루프 전용) */
		if (fl_wait && c.ack_seq == fl_wait_seq) {
			fl_acked = true;
			break;
		}
		if (atomic_get(&g_state) != PSTAT_RUN &&
		    (fl_wait || flog_pending() > 0)) {
			/* 재생 국면(비측정+백로그)의 기타 ack: 옛 세션 seq 가 라이브
			 * seq 와 겹칠 수 있으므로 RAM 에 적용 금지 (오해제 방지).
			 * 측정 중엔 라이브 스트림의 ack 이므로 정상 적용. */
			break;
		}
		databuf_ack(c.ack_seq);
		break;
	case CMD_STOP:
		stop_req = true;
		LOG_INF("cmd: stop");
		break;
	case CMD_CONFIG:
		k_mutex_lock(&cfg_lock, K_FOREVER);
		g_cfg = c.cfg;
		k_mutex_unlock(&cfg_lock);
		if (c.hw_changed) {
			store_save_hw(&c.cfg);   /* rf/os 는 NVM 영속화 */
			LOG_INF("cmd: config (rf=%u os=%u saved)", c.cfg.rf_ohm,
				c.cfg.oversample);
		} else {
			LOG_INF("cmd: config");
		}
		break;
	case CMD_START:
		k_mutex_lock(&cfg_lock, K_FOREVER);
		g_cfg = c.cfg;
		k_mutex_unlock(&cfg_lock);
		if (c.hw_changed) {
			store_save_hw(&c.cfg);
		}
		if (low_batt) {
			LOG_WRN("cmd: start 거부 (저전압 %dmV)", g_vbat_mv);
			status_req = true;
			break;
		}
		if (atomic_cas(&g_state, PSTAT_IDLE, PSTAT_RUN)) {
			stop_req = false;
			k_sem_give(&start_sem);
			LOG_INF("cmd: start");
		} else {
			LOG_WRN("cmd: start 무시 (이미 실행중 — stop 먼저)");
		}
		break;
	case CMD_ZERO:
	case CMD_CAL:
		if (atomic_cas(&g_state, PSTAT_IDLE, PSTAT_RUN)) {
			cal_req = (c.type == CMD_ZERO) ? 1 : 2;
			cal_kohm = c.cal_kohm;
			stop_req = false;
			k_sem_give(&start_sem);
			LOG_INF("cmd: cal (kind=%u kohm=%u)", cal_req, cal_kohm);
		} else {
			LOG_WRN("cmd: cal 무시 (측정중 — stop 먼저)");
		}
		break;
	case CMD_STATUS:
		status_req = true;
		break;
	default:
		break;
	}
}

static void nus_send_enabled(enum bt_nus_send_status status)
{
	notif_enabled = (status == BT_NUS_SEND_STATUS_ENABLED);
	LOG_INF("NUS notify %s", notif_enabled ? "ENABLED" : "disabled");
}

static struct bt_nus_cb nus_cb = {
	.received = nus_received,
	.send_enabled = nus_send_enabled,
};

static int tx_nus(const uint8_t *data, uint16_t len)
{
	if (!notif_enabled) {
		return -ENOTCONN;
	}
	struct bt_conn *c = conn_get();
	if (!c) {
		return -ENOTCONN;
	}
	int err = bt_nus_send(c, data, len);
	bt_conn_unref(c);
	return err;
}

/* ===================== 데이터/상태 전송 ===================== */
#define BATCH_MAX   5
#define DRAIN_ITERS 8
#define FL_ACK_TICKS 100   /* 플래시 배치 ack 대기 2s (20ms tick) — 초과 시 재전송 */

/* 플래시 백로그 재생 상태 (stop-and-wait: 배치 ack 후 다음 배치) */
static volatile bool     fl_wait;      /* 배치 전송 후 ack 대기중 */
static volatile bool     fl_acked;     /* BLE 스레드가 ack 수신 표시 */
static volatile uint32_t fl_wait_seq;  /* 대기중 배치의 마지막 seq */
static uint32_t          fl_wait_n;
static uint32_t          fl_wait_tick;

/* 샘플 배치 → {"d":[...]} 전송. 0=성공 */
static int send_batch(const struct pstat_sample *b, uint32_t k)
{
	static char dline[256];
	int o = snprintk(dline, sizeof(dline), "{\"d\":[");
	for (uint32_t i = 0; i < k; i++) {
		size_t rem = (o < (int)sizeof(dline)) ? sizeof(dline) - o : 0;
		o += snprintk(dline + o, rem, "%s[%u,%u,%.3f,%u]",
			i ? "," : "", b[i].seq, b[i].t_ms,
			(double)b[i].current_nA, b[i].range_idx);
	}
	{
		size_t rem = (o < (int)sizeof(dline)) ? sizeof(dline) - o : 0;
		o += snprintk(dline + o, rem, "]}\n");
	}
	if (o >= (int)sizeof(dline)) {
		return -EMSGSIZE;
	}
	return tx_nus(dline, o);
}
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
int main(void)
{
	int err;

	LOG_INF("=== discrete potentiostat (nRF52832 SAADC, app-controlled) ===");

	if (meas_init() != 0) {
		LOG_ERR("meas init failed");
		return 0;
	}
	store_init(&g_cfg, &g_cal);   /* NVM 에서 rf/os/cal 로드 */

	err = bt_enable(NULL);
	if (err) {
		LOG_ERR("bt_enable failed (%d)", err);
		return 0;
	}
	bt_nus_init(&nus_cb);
	start_advertising();
	battery_check();
	flog_init();   /* 플래시 백로그 복원 (실패해도 RAM 전용으로 계속 동작) */
	LOG_INF("ready. rf=%u os=%u scale=%.4f vbat=%dmV",
		g_cfg.rf_ohm, g_cfg.oversample, (double)g_cal.scale, g_vbat_mv);

	uint32_t tick = 0;
	struct pstat_sample batch[BATCH_MAX];

	while (1) {
		k_msleep(20);
		tick++;

		/* 배터리: 10분마다 (측정 중에도 — SAADC 채널 분리라 간섭 없음) */
		if ((tick % (VBAT_PERIOD_MS / 20)) == 0) {
			battery_check();
		}
		/* 유휴+미연결: LED 짧은 블링크 (광고 표시) */
		if (!current_conn && atomic_get(&g_state) == PSTAT_IDLE) {
			led_set((tick % 100) < 3);   /* 2초마다 60ms */
		}

		if (!current_conn || !notif_enabled) {
			fl_wait = false;    /* 재연결하면 백로그 tail 부터 다시 */
			fl_acked = false;
			/* 오프라인: RAM 링 → 플래시 백로그 이동 (웨어러블 핵심 경로).
			 * 옮긴 만큼 RAM 에서 해제 → RAM 은 짧은 대기실 역할만 */
			for (int it = 0; it < DRAIN_ITERS; it++) {
				uint32_t base;
				uint32_t k = databuf_peek_batch(batch, BATCH_MAX, &base);
				if (k == 0) {
					break;
				}
				uint32_t ok = 0;
				while (ok < k && flog_push(&batch[ok]) == 0) {
					ok++;
				}
				if (ok > 0) {
					databuf_commit_sent(base, ok);
					databuf_ack(base + ok - 1);
				}
				if (ok < k) {
					break;   /* 플래시 사용불가 → RAM 링 유지(기존 동작) */
				}
			}
			if ((tick % 250) == 0) {
				LOG_INF("alive up=%us state=%ld fpend=%u buf=%u vbat=%d conn=%d",
					k_uptime_get_32() / 1000U, atomic_get(&g_state),
					flog_pending(), databuf_unacked(),
					g_vbat_mv, current_conn ? 1 : 0);
			}
			continue;
		}

		/* 연결됨: 플래시 백로그 재생은 **측정 중이 아닐 때만** (IDLE/휴지기).
		 * 이유: ① 코인셀 IR 로 라디오 버스트가 전압 새그 유발 — 측정 부하와
		 * 겹치지 않게, ② 재생 라디오 노이즈가 아날로그 측정에 침투 방지.
		 * stop-and-wait: 배치 ack 확인 후 다음 배치 (ack 유실 시 재전송,
		 * 중복은 앱 파서가 seq 로 걸러냄). */
		bool measuring = (atomic_get(&g_state) == PSTAT_RUN);

		if (measuring) {
			fl_wait = false;    /* 재생 일시정지 — 측정 끝나면 tail 부터 재개 */
			fl_acked = false;
		} else {
			if (fl_wait) {
				if (fl_acked) {
					flog_free_batch(fl_wait_n);
					fl_wait = false;
					fl_acked = false;
				} else if ((uint32_t)(tick - fl_wait_tick) > FL_ACK_TICKS) {
					fl_wait = false;   /* 타임아웃 → 같은 배치 재전송 */
				}
			}
			if (!fl_wait && flog_pending() > 0) {
				uint32_t k = flog_peek_batch(batch, BATCH_MAX);
				if (k == 0) {
					flog_free_batch(1);   /* 손상 레코드 스킵 (livelock 방지) */
				} else if (send_batch(batch, k) == 0) {
					fl_wait = true;
					fl_acked = false;
					fl_wait_seq = batch[k - 1].seq;
					fl_wait_n = k;
					fl_wait_tick = tick;
				}
			}
		}

		/* 라이브 드레인 (무손실: 전송 성공한 배치만 절대위치 commit).
		 * 측정 중엔 항상 (백로그는 일시정지 상태) / 유휴·휴지기엔
		 * 백로그가 다 빠진 뒤에만 — 시간순 보존 */
		if (measuring || (!fl_wait && flog_pending() == 0)) {
			for (int it = 0; it < DRAIN_ITERS; it++) {
				uint32_t base;
				uint32_t k = databuf_peek_batch(batch, BATCH_MAX, &base);
				if (k == 0) {
					break;
				}
				if (send_batch(batch, k) == 0) {
					databuf_commit_sent(base, k);
				} else {
					break;
				}
			}
		}

		if (status_req || (tick % 50) == 0) {
			status_req = false;
			tx_status();
		}
	}
	return 0;
}

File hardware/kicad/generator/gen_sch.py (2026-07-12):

#!/usr/bin/env python3
"""Generate discrete-potentiostat.kicad_sch (KiCad 7) + expected netlist.

Style: every connected pin gets a short stub wire + local net label (or a power
symbol whose anchor sits on the stub end). Rot-0 placement only -> transform is
(X + px, Y - py). Verified against kicad-cli netlist export.
"""
import os, re, uuid, json

GEN = os.path.dirname(os.path.abspath(__file__))
OUT = '/home/user/ad5941/discrete-potentiostat/hardware/kicad'

def U(): return str(uuid.uuid4())

# ---------------------------------------------------------------- symbols ---
def load(name):
    return open(os.path.join(GEN, name + '.sym')).read()

def rename_block(blk, old, new):
    blk = blk.replace('(symbol "%s"' % old, '(symbol "%s"' % new, 1)
    blk = blk.replace('(symbol "%s_' % old, '(symbol "%s_' % new)
    return blk

def set_property(blk, prop, value):
    pat = r'(\(property "%s" ")[^"]*(")' % prop
    if re.search(pat, blk):
        return re.sub(pat, r'\g<1>%s\g<2>' % value, blk, count=1)
    return blk

def prefix_libname(blk, name, libid):
    # outer name -> full lib id, inner unit names keep bare name
    return blk.replace('(symbol "%s"' % name, '(symbol "%s"' % libid, 1)

CUSTOM_REF35 = '''(symbol "pstat:REF35102QDBVR" (in_bom yes) (on_board yes)
      (property "Reference" "U" (at -7.62 11.43 0) (effects (font (size 1.27 1.27))))
      (property "Value" "REF35102QDBVR" (at 0 -13.97 0) (effects (font (size 1.27 1.27))))
      (property "Footprint" "Package_TO_SOT_SMD:SOT-23-6" (at 0 -16.51 0) (effects (font (size 1.27 1.27)) hide))
      (property "Datasheet" "https://www.ti.com/lit/ds/symlink/ref35.pdf" (at 0 0 0) (effects (font (size 1.27 1.27)) hide))
      (property "Description" "1.024V ultra-low-power precision voltage reference, SOT-23-6" (at 0 0 0) (effects (font (size 1.27 1.27)) hide))
      (symbol "REF35102QDBVR_0_1"
        (rectangle (start -7.62 7.62) (end 7.62 -7.62)
          (stroke (width 0.254) (type default)) (fill (type background)))
      )
      (symbol "REF35102QDBVR_1_1"
        (pin power_in line (at 2.54 10.16 270) (length 2.54)
          (name "VIN" (effects (font (size 1.27 1.27))))
          (number "4" (effects (font (size 1.27 1.27)))))
        (pin input line (at -10.16 0 0) (length 2.54)
          (name "EN" (effects (font (size 1.27 1.27))))
          (number "3" (effects (font (size 1.27 1.27)))))
        (pin power_out line (at 10.16 2.54 180) (length 2.54)
          (name "VREF" (effects (font (size 1.27 1.27))))
          (number "6" (effects (font (size 1.27 1.27)))))
        (pin passive line (at 10.16 -2.54 180) (length 2.54)
          (name "NR" (effects (font (size 1.27 1.27))))
          (number "5" (effects (font (size 1.27 1.27)))))
        (pin power_in line (at -2.54 -10.16 90) (length 2.54)
          (name "GND" (effects (font (size 1.27 1.27))))
          (number "2" (effects (font (size 1.27 1.27)))))
        (pin power_in line (at 2.54 -10.16 90) (length 2.54)
          (name "GND" (effects (font (size 1.27 1.27))))
          (number "1" (effects (font (size 1.27 1.27)))))
      )
    )'''


CUSTOM_FL = '''(symbol "pstat:2450FM07A0029" (in_bom yes) (on_board yes)
      (property "Reference" "FL" (at -5.08 6.35 0) (effects (font (size 1.27 1.27))))
      (property "Value" "2450FM07A0029" (at 0 -6.35 0) (effects (font (size 1.27 1.27))))
      (property "Footprint" "pstat:Johanson_0402_4pin" (at 0 -8.89 0) (effects (font (size 1.27 1.27)) hide))
      (property "Datasheet" "https://www.johansontechnology.com/docs/1329/2450FM07A0029_yx4cUdW.pdf" (at 0 0 0) (effects (font (size 1.27 1.27)) hide))
      (property "Description" "2.45GHz impedance-matched LPF for nRF52832/810/811 QFN, EIA 0402 4-pin" (at 0 0 0) (effects (font (size 1.27 1.27)) hide))
      (symbol "2450FM07A0029_0_1"
        (rectangle (start -5.08 3.81) (end 5.08 -3.81)
          (stroke (width 0.254) (type default)) (fill (type background)))
      )
      (symbol "2450FM07A0029_1_1"
        (pin passive line (at -7.62 0 0) (length 2.54)
          (name "IN" (effects (font (size 1.27 1.27))))
          (number "1" (effects (font (size 1.27 1.27)))))
        (pin passive line (at -2.54 -6.35 90) (length 2.54)
          (name "GND" (effects (font (size 1.27 1.27))))
          (number "2" (effects (font (size 1.27 1.27)))))
        (pin passive line (at 7.62 0 180) (length 2.54)
          (name "OUT" (effects (font (size 1.27 1.27))))
          (number "3" (effects (font (size 1.27 1.27)))))
        (pin passive line (at 2.54 -6.35 90) (length 2.54)
          (name "GND" (effects (font (size 1.27 1.27))))
          (number "4" (effects (font (size 1.27 1.27)))))
      )
    )'''


CUSTOM_ANT = '''(symbol "pstat:2450AT07A0100" (in_bom yes) (on_board yes)
      (property "Reference" "E" (at -3.81 6.35 0) (effects (font (size 1.27 1.27))))
      (property "Value" "2450AT07A0100" (at 0 -8.89 0) (effects (font (size 1.27 1.27))))
      (property "Footprint" "pstat:Johanson_2450AT07A0100" (at 0 -11.43 0) (effects (font (size 1.27 1.27)) hide))
      (property "Datasheet" "https://www.johansontechnology.com/docs/4417/Antenna-2450AT07A0100001T.pdf" (at 0 0 0) (effects (font (size 1.27 1.27)) hide))
      (property "Description" "2.44GHz chip antenna, EIA 0402, 4-terminal: 1/4 Feed, 2/3 GND (Doc# 36S0021A Rev 4.1)" (at 0 0 0) (effects (font (size 1.27 1.27)) hide))
      (symbol "2450AT07A0100_0_1"
        (rectangle (start -3.81 3.81) (end 3.81 -5.08)
          (stroke (width 0.254) (type default)) (fill (type background)))
        (polyline (pts (xy 0 3.81) (xy 0 5.08) (xy -1.27 6.35) (xy 1.27 6.35) (xy 0 5.08))
          (stroke (width 0.254) (type default)) (fill (type none)))
      )
      (symbol "2450AT07A0100_1_1"
        (pin passive line (at -6.35 1.27 0) (length 2.54)
          (name "FEED" (effects (font (size 1.27 1.27))))
          (number "1" (effects (font (size 1.27 1.27)))))
        (pin passive line (at -6.35 -1.27 0) (length 2.54)
          (name "FEED" (effects (font (size 1.27 1.27))))
          (number "4" (effects (font (size 1.27 1.27)))))
        (pin passive line (at -1.27 -7.62 90) (length 2.54)
          (name "GND" (effects (font (size 1.27 1.27))))
          (number "2" (effects (font (size 1.27 1.27)))))
        (pin passive line (at 1.27 -7.62 90) (length 2.54)
          (name "GND" (effects (font (size 1.27 1.27))))
          (number "3" (effects (font (size 1.27 1.27)))))
      )
    )'''
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

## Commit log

2026-07-10 Add discrete-potentiostat design: OPA2391 dual-amp CA device with Qi charging
    New folder for the miniature 3-electrode chronoamperometry device built
    without the AD5941: OPA2391 (control amp + TIA), REF35102 1.024V reference,
    nRF52832 SAADC differential measurement, MIC5205-3.3, BQ51050B Qi receiver
    charging a LIR2032 coin cell.
    - README: part roles and signal chain
    - hardware/design.md: bias network (+0.4995V), TIA sizing, SAADC gain
    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
2026-07-10 Simplify bias to 1:1 divider (+0.512V), justify RF=1M + oversampling for 1nA
    - Bias: exact 0.5V not required, so use matched 1.00M/1.00M divider ->
    E = +0.512V fixed; 1% resistors suffice
    - Add RF trade-off analysis (1M + 64x oversampling vs 10M): both meet the
    1nA resolution requirement, 1M chosen for uA-range coverage; keep 10M
    swap footprint for sensors confirmed under ~200nA
    - Firmware plan: clarify the measurement core is a from-scratch rewrite
    (nRF SAADC measures directly; no AD5941 SPI code survives), only the
    BLE/buffering/protocol layers carry over
    Claude-Session: https://claude.ai/code/session_01GUNJUwfGKqvkZFmTaLQRu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
2026-07-10 Firmware plan: make RF value and oversampling runtime-configurable
    RF/CF are swappable passives, so the firmware must not hardcode them:
    rf_ohm and oversample become NVM-backed settings changeable over BLE
    config. Swapping RF then only needs soldering + config + one dummy-cell
    calibration, no reflash.
    Claude-Session: https://claude.ai/code/session_01GUNJUwfGKqvkZFmTaLQRu3
2026-07-10 Add verified KiCad schematic for the discrete potentiostat
    Complete single-sheet KiCad 7 schematic (symbols embedded, opens without
    extra libraries) covering all four blocks: BQ51050B Qi receiver/charger,
    LIR2032 + MIC5205 power, OPA2391+REF35102 AFE, MDBT42Q nRF52832 module.
    Accuracy work:
    - BQ51050BRHL and MIC5205 pin maps taken from the official KiCad library;
    OPA2391 (DGK) and REF35 (DBV) pinouts confirmed against datasheets
    - MDBT42Q 41-pad symbol: pads 1-21/37-41 web-verified, 22-36 reconstructed;
    every pad actually used in the design is a verified one
    - Charge current network corrected: no ISET pin on BQ51050B -- IBULK =
    314/RILIM via ILIM/FOD (15.4k+200R = 20mA), TERM 2.4k = 1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
    [discrete-potentiostat.kicad_sch]
2026-07-10 Replace BQ51050B direct-charge with BQ51013B + MCP73832 two-stage charging
    Resolves the coin-cell charging risk: TI states BQ5105xB does not regulate
    well below ~200mA, unsuitable for a 40mAh LIR2032. New chain follows TI's
    guidance (Qi receiver -> 5V rail -> dedicated low-current charger), using
    hand-solderable packages instead of the WCSP-only BQ51003/BQ25100 combo:
    - BQ51013BRHLR: Qi WPC v1.2 receiver, regulated 5V out, VQFN-20. Pin map
    is the verified BQ51050BRHL family symbol with the two differing pins
    confirmed against the datasheet (4 OUT, 10 EN1). EN1=EN2=GND enables
    wireless; ILIM RILIM=250/IMAX -> 2.52k = 100mA; NTC stays on TS/CTRL.
    - MCP73832T-2ACI/OT (official KiCad symb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
    [discrete-potentiostat.kicad_sch]
2026-07-10 Fix module part number: MDBT42Q-512KV2 (no 1MV2 variant exists for nRF52832)
    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
    [discrete-potentiostat.kicad_sch]
2026-07-10 Add module-vs-chipdown size/cost review: keep MDBT42Q
    Final device size is pinned by the Qi coil (26.3mm) and LIR2032 (20mm),
    not the MCU: chip-down saves ~50mm2 (4% of the 28mm disc PCB) and shrinks
    the enclosure by zero. Per-unit saving ~$1 vs $13-25k RF/cert NRE puts
    break-even at ~15-25k units. Includes a placement plan for the 28mm puck.
    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
2026-07-10 Swap Qi coil to 760308101214 (19mm/26uH): smaller AND cheaper
    The 26.3mm coil was a part-selection artifact, not a requirement — the
    original sizing logic (device bounded by the battery) is restored. The
    19mm WE-WPCC receiver coil costs less (~$7 vs ~$11), shrinks the PCB
    from ~28mm to ~23mm disc, and our 0.13W charge load easily tolerates the
    reduced coupling. Resonant caps retuned: C1 56n->100n, C2 560p->1n C0G.
    Schematic regenerated, netlist re-verified (PASS); size/cost review
    updated to the battery-bounded premise.
    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
    [discrete-potentiostat.kicad_sch]
2026-07-10 Swap Qi coil to TDK WR202010-18M8-ID (20x20x1.0mm, 11uH, ~$3.6)
    Cheapest verified candidate (half the 19mm Wurth) with the same footprint
    class as the battery. Square outline: 22x22mm rounded-square puck instead
    of a round disc (20x20 diagonal is 28.3mm). Resonant caps retuned for
    11uH: C1 220nF C0G (fs 102kHz), C2 2.2nF C0G (fd ~1MHz). Schematic
    regenerated, netlist verified (PASS).
    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
    [discrete-potentiostat.kicad_sch]
2026-07-10 Switch MCU to chip-down nRF52832-QFAA per user decision
    Module certification inheritance is moot (intentional-radiator cert is
    budgeted anyway), so the design drops MDBT42Q for the bare chip:
    - nRF52832-QFAA on the verified official KiCad symbol (48+EP pin map)
    - 32MHz crystal (CL 8pF) + 12pF loads; no 32k crystal -> LFRC synth
    - RF front-end: Johanson 2450FM07A0029 (nRF52-QFN-specific matched LPF,
    replaces discrete LC guesswork) -> 0R/DNP tee tuning slots ->
    2450AT18B0100001E chip antenna
    - Nordic QFN48 reference decoupling: DEC1 100n, DEC4 1u, DEC2/DEC3 NC,
    VDD 100n x3 + 4.7u bulk, DCC->DEC4 via 10uH+15nH (LDO-safe if unused)
    - Same GPIO functions remapped to chip pins (AIN0/1/2 = 4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
    [discrete-potentiostat.kicad_sch]
2026-07-11 Redraw REF35102 and OPA2391 symbols per user's preferred style
    - REF35102QDBVR: VIN on top, EN left, VREF/NR right, GND pins 1/2 on the
    bottom (same verified pin numbers, new geometry)
    - OPA2391DGKR: single-box dual op amp (A/B triangles inside, inputs left,
    outputs right, V+ top pin 8, V- bottom pin 4) replacing the three-unit
    LM2904-style symbol; one U4 instance carries all 8 pins
    Netlist unchanged and re-verified: 47 nets PASS.
    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
    [discrete-potentiostat.kicad_sch]
2026-07-11 Swap chip antenna to Johanson 2450AT07A0100 (0402 micro)
    Smallest Johanson 2.4GHz antenna (1.0x0.5x0.37mm). Datasheet ground
    keepout must be followed exactly; the existing R15/C34 tee slots handle
    on-board tuning. Netlist re-verified (47 nets PASS).
    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
    [discrete-potentiostat.kicad_sch]
2026-07-11 Complete antenna tee tuning network (series-shunt-series per Johanson)
    Adds R16 (0R) after the C34 shunt slot so the full tee recommended by
    Johanson is available for on-board antenna tuning. Radio-side matching
    needs no discrete LC: FL1 (2450FM07A0029) is the complete impedance
    match + harmonic LPF for the nRF52832 ANT output. Netlist PASS.
    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
    [discrete-potentiostat.kicad_sch]
2026-07-11 Antenna tuning: switch tee to pi (shunt-series-shunt) per 2450AT07A0100 datasheet
    The 0402 micro antenna's datasheet states non-eval PCBs will require a
    pi network for proper resonance (eval board alone gets away with 0R).
    Slots: C35 (DNP) - R15 (0R) - C34 (DNP). Also documents the keepout:
    ~5x3mm copper-free zone on all layers at the board corner; battery can
    and Qi coil must stay out from under it. Netlist PASS.
    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
    [discrete-potentiostat.kicad_sch]
2026-07-11 Add PCB layout: 24x22mm 4-layer, placement complete and verified
    Generated with the pcbnew API from the schematic netlist (all 70
    footprints, 77 nets assigned). Verified zero courtyard overlaps and zero
    board-edge violations via generator/check_pcb.py after an automated
    legalization pass.
    - Floorplan: Qi charger top-left (coil lead pads on left edge), RF corner
    top-right with the 5x3mm all-layer antenna keepout (rule area: no pours
    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
    [discrete-potentiostat.kicad_pcb, discrete-potentiostat.kicad_sch]
2026-07-11 Auto-route PCB: GND planes stitched, ~90% of signals routed, rules set
    Custom A* grid router (generator/route_pcb.py) over F.Cu/B.Cu with via
    moves, rip-up-and-reroute, long-net bottom-layer bias, and a RESUME mode
    that preserves existing copper and routes only unconnected endpoints.
    GND handled by 4-layer pours + shared stitching vias; RF feed untouched.
    Board design rules aligned to the routed geometry (0.09 min track/clear,
    0.4/0.2 via -> within JLC 4-layer capability), which reduces real DRC
    electrical findings to: 39 unconnected pads (~20 links, clustered at the
    charger cap bank and the nRF south-west flank), 12 clearance, 3 hole.
    Full report in hardware/kicad/drc-report.txt; interacti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
    [discrete-potentiostat.kicad_pcb]
2026-07-11 6-layer PCB + solder-pad connectors: auto-routing reaches ~92%
    Per user decisions: (1) J1/J2 pin headers replaced with 1.0mm round
    solder pads (1.8mm pitch) for direct wire soldering - also removes THT
    barrels from inner layers; (2) board upgraded 4 -> 6 layers
    (L1 sig/RF, L2 GND, L3/L4 routing, L5 GND, L6 sig+battery pads).
    Router upgraded to 4 routing layers with through-vias, DRC-driven todo
    override for RESUME runs, self-rip protection for large nets, and design
    rules baked into generation (0.09/0.09, via 0.4/0.2). Result: unrouted
    links 20 (4-layer) -> 8 (6-layer); 7 clearance items; finish guide in the
    README (KiCad push-and-shove, ~30min). DRC report refreshed.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
    [discrete-potentiostat.kicad_pcb, discrete-potentiostat.kicad_sch]
2026-07-11 Swap op amp to LPV802 (nanopower) per user request
    LPV802DGKR: 320nA/ch, 0.1pA input bias, 8kHz GBW, VSSOP-8 — same package
    and standard dual pinout as the OPA2391 it replaces, so the PCB keeps its
    routing (value updated in place). AFE rail drops to ~2uA total.
    Trade-off documented: +/-3.5mV max offset -> +/-3.5nA fixed TIA offset at
    RF=1M, removed by the existing zero-calibration step; pin-compatible
    LPV812 (+/-0.3mV) noted as the precision upgrade. Netlist re-verified.
    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
    [discrete-potentiostat.kicad_pcb, discrete-potentiostat.kicad_sch]
2026-07-11 Sync PCB generator scripts (26x24 double-sided) + doc size updates
    - gen_pcb.py: 26x24mm 6-layer, double-sided placement (ICs top, passives
    on back ring outside the LIR2032 battery zone), relative output paths
    - route_pcb.py: 4 routing layers (F/In2/In3/B), pad-core inset fix,
    RESUME mode with todo_override.json, rip-up victim filter
    - new: final_fix.py (bridge stray DRC-unconnected pads), route_loop.sh
    (DRC -> todo -> RESUME convergence loop), check_pcb.py battery-zone check
    - docs: board size finalized at 26x24mm (routability margin, user-approved)
    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
2026-07-11 Regenerate 26x24 double-sided PCB placement (routing in progress)
    The previously routed board file was accidentally overwritten by a DRC
    report; regenerated from gen_pcb.py (placement + zones + keepout + RF
    pre-route). Full auto-route re-run follows in the next commit.
    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
    [discrete-potentiostat.kicad_pcb]
2026-07-11 WIP: re-route pass for last 3 links at BQ51013B corner
    Ripped RECT/V5OUT/FOD/TS corridor blockers; router re-running with
    CLAMP2/BOOT2/COMM2 prioritized. Final routed board follows.
    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
    [discrete-potentiostat.kicad_pcb]
2026-07-11 PCB fully auto-routed: 0 unconnected, 0 copper DRC violations
    - Re-route with net priority cracked the BQ51013B QFN corner: ripped
    RECT/V5OUT/FOD/TS corridor blockers, routed CLAMP2/BOOT2/COMM2 first,
    re-routed the ripped nets after (route_pcb.py PRIORITY env)
    - GND cleanup: stitched orphan pads (U1.9/C32/R2/C23/C24) with vias,
    stitched isolated zone islands, sub-0.7mm2 slivers auto-removed
    - RF feed re-routed with clearance-validated paths: ANT (U3.30->FL1)
    approaches pad from south clear of GND pads; ANT50 runs south around
    C35; ANT_FEED rounds C34 east into the chip antenna
    - C1 moved +0.22/+0.46mm off the rounded board corner (was outside the
    edge-clearance arc); connectivity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
    [discrete-potentiostat.kicad_pcb]
2026-07-11 Shrink board to 23.4x22mm (RevC, -17.5%); 4-layer ruled out
    Size floor analysis: width bound by LIR2032 tab pads (+/-9.8mm + pad +
    edge), height by the O21 cell zone -> 23.4x22 is the practical minimum
    without changing the battery/tab structure.
    - RevC placement: ICs on top; back reduced to 4 corner pockets (R1/R2/
    TH1, R3, R5/R6/C15); J2 SWD pads + TP1-3 moved to the front right
    column (clears the battery, easier soldering); DCDC inductors L2/L3
    relocated next to U3.46/47 (fixed the persistent DCC/DEC4 congestion);
    C30 rotated 180deg so DEC1 faces the open channel
    - Routing: auto-route + priority/rip convergence to 4 links, then
    validated hand paths (close4.py): DCC via-in-pad U3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
    [discrete-potentiostat.kicad_pcb]
2026-07-11 Firmware for the discrete board: nRF52832 SAADC measurement engine
    New app under discrete-potentiostat/firmware/ replacing the AD5941 SPI
    path with direct SAADC measurement, per firmware-plan.md. The BLE
    protocol stays wire-compatible with the existing Android app.
    - meas.c: differential SAADC (AIN1 TIA_OUT vs AIN0 VREF 1.024V), 3-step
    gain table {4, 1, 1/2} (FS +/-150nA .. +/-2.1uA @1M), HW oversampling
    (1..256, runtime), 40us acquisition, recalibration on gain change;
    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
2026-07-12 Fix E1 antenna to datasheet-true 4-terminal land pattern (GND connected)
    Johanson 2450AT07A0100 datasheet (36S0021A Rev 4.1) defines 4 terminals:
    1/4 = Feed, 2/3 = GND. Previous footprint was a wrong 2-pad guess with
    the GND end floating.
    - gen_pcb.py: 4-pad footprint (0.3x0.25 pads, rows +-0.3 along L,
    columns +-0.175 across W per eval-board land pattern); E1 moved to
    (19.4, 0.95) rot 270 - vertical edge mount, GND row toward top edge;
    parametric feed bridge to R15.2 and 0.3mm GND strip into left F pour
    - gen_sch.py: custom 4-pin antenna symbol (1/4 ANT_FEED, 2/3 GND);
    netlist check PASS (47 nets)
    - Board file: live surgery applied (new E1 + feed bridge + GND strip,
    old 2-pad E1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
    [discrete-potentiostat.kicad_pcb, discrete-potentiostat.kicad_sch]
2026-07-12 Retarget firmware to user schematic pinmap + Qi pad detection
    Pin map changes (user-drawn schematic, 2026-07-12):
    - SAADC differential swapped: AIN0 = TIA_OUT (+), AIN1 = VREF (-)
    - AFE power (AVDD direct GPIO feed) moved P0.06 -> P0.07 high-drive;
    schematic requirement: remove always-on DVDD->AVDD link (R7)
    - New Qi pad sense on P0.05/AIN3 (MCP73832_VDD 1M:1M divider):
    meas_qi_mv()/meas_qi_present(), status JSON gains "qi" field
    (chg = actually charging via STAT, qi = on charging pad)
    - LED now optional on P0.06 (unpopulated by default, harmless)
    - LDO regulator mode (DCC pin unconnected on this board) - removed
    DCDC overlay override
    - README/headers updated with final pin table and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
    [main.c, meas.c]
2026-07-12 Move AFE power (AVDD feed) pin P0.07 -> P0.12
    Any plain GPIO works for the ~2uA AVDD feed; P0.12 chosen for
    schematic/layout convenience. P0.07 returns to the free-pin pool.
    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
2026-07-12 Move AFE power (AVDD feed) pin to P0.26 per user schematic rev2
    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
2026-07-12 Default rf_ohm 1M -> 2M to match user board TIA feedback (R9 = 2M)
    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
2026-07-12 Document user-board design review and final parameters
    - user-board-review.md: confirmed pin map, power topology (charge
    always-on / switch-gated system / GPIO-gated AFE), resonance and
    charge-current values for the 760308101214 coil, passive size and
    voltage-rating rules (which caps cannot be 0402 and why), app-side
    battery gauge guidance, and remaining tasks
    - user-board-schematic.pdf: reviewed final schematic (rev4)
    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
2026-07-13 Flash offline backlog for wearable use (measure without phone)
    New flog module: 96KB internal-flash ring (24 x 4KB pages, 16B records
    with CRC8 + marker, monotonic page numbers) holding ~6,100 samples =
    ~10 h of cycle-mode data. Survives reboot/System OFF.
    Data path: while BLE is disconnected the main loop moves RAM ring
    samples into flash; on reconnect the backlog replays oldest-first
    through the existing {"d":...}+ack stream (batch stop-and-wait with
    resend on ack timeout), then live streaming resumes - existing app
    works unmodified. Acks arriving during replay are never applied to the
    live RAM buffer (old-session seq numbers may collide with live ones).
    Overflow recycles the oldest page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
    [main.c]
2026-07-13 Pause backlog replay while measuring (sync only in idle/rest)
    Radio TX bursts on a high-IR coin cell sag the supply; overlapping them
    with the measurement phase risks both brownout near cutoff and radio
    noise coupling into the analog front end. Backlog replay now runs only
    in IDLE/CYCLE_REST; live streaming behaves as before during runs, and
    ack routing follows the phase (live acks apply normally while
    measuring).
    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
    [main.c]
2026-07-13 Add agg summary mode: one integral-slope sample per measurement phase
    With "agg":1 in config/start, raw samples are discarded and each
    CYCLE/TIMED measurement phase emits a single sample whose value is the
    slope of a linear fit of Q(t) = trapezoid-integrated charge over the
    last 50% of the phase - a noise-robust estimate of the steady-state
    current (the "end value" the user actually consumes). Falls back to
    the last current if the fit is degenerate; partial phases still emit
    when >= 2 fit points exist. CONTINUOUS ignores agg (raw stream).
    Cuts storage and radio volume ~50x at 10 Hz / 5 s phases: flash
    backlog capacity goes from ~10 h to ~21 days of 5-min cycles. Status
    JSON reports "agg"; p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
    [main.c]
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2026-07-13 Mockup v0.3: adaptive time-axis ticks on the main graph
    X-axis now draws round-time tick lines and labels whose interval
    adapts to the zoom level (30 min / 1 h / 3 h / 6 h / 12 h / 1 d / 2 d,
    picked so <= 6 ticks are visible); daily ticks label as M/D, finer
    ones as HH:MM. Replaces the bare start/end corner labels.
    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
2026-07-13 Mockup v0.4: electrode-swap markers + unambiguous device battery
    - Electrode replacement events (app-recorded) render as dashed vertical
    markers with a tag on the main graph; also surfaced in the log tab
    and a new settings section with a "record replacement" button and
    days-since counter shown on the home device card
    - Device battery moved out of the app bar (where it read like the
    phone's) into a home device-status card: ring gauge explicitly
    labeled "기기 배터리" alongside connection/charging-pad state
    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
2026-07-13 Mockup v0.5: QR-based electrode registration flow
    Electrode swaps will be registered by scanning a QR on the electrode:
    settings gains a primary "scan electrode QR" button opening a scan
    sheet (mock camera -> recognizes ID/lot/expiry -> register updates the
    current-electrode card and days-since counter), with manual recording
    kept as a fallback for damaged codes. Electrode ID now appears on the
    home device card and in log events. Open question added: whether the
    QR payload should carry a per-lot calibration factor so swaps skip the
    dummy-cell scale step.
    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
2026-07-13 Mockup v0.6: merge graph tab into home
    The graph tab duplicated the home screen, so it's gone: the home
    sparkline slot is now the full interactive chart (pan/zoom, tap-point
    tooltip, adaptive time ticks, electrode markers, reset) with
    visible-window stats tiles below; nav is down to home/log/settings.
    Also fixed device-card label wrapping.
    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
2026-07-13 Mockup v0.7: one-screen home, server day-view log, account settings
    - Home now fits 812px with no scroll: compact hero (value + range pill
    inline), slim sync banner, chart, and a single 4-cell stats strip;
    all graph interactions unchanged
    - Log tab reworked into server-backed day browsing: prev/next date
    navigation loads that day's full 00-24h graph (fixed axis, 6h ticks,
    electrode markers), day stats, and that day's events; demo keeps 7
    days
    - Settings tab is now account/service-centric: Google profile card,
    server auto-upload / last upload / Wi-Fi-only, notification toggles,
    electrode QR; device/firmware details demoted behind a "measurement
    details >" row; logout at bottom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
2026-07-13 Mockup v0.8: day-view pan/zoom + turning-point value labels
    Chart logic refactored into a shared zoomChart factory; the log tab's
    day view now has the same drag-pan / pinch-wheel zoom / tap-to-inspect
    / reset interactions as home, clamped to the selected day. Turning
    points are auto-detected on the day curve (9-sample smoothing, then a
    zigzag extrema filter with >= 5 nA prominence) and rendered as diamond
    markers with rounded value labels above peaks / below valleys, with a
    density cap to avoid clutter when zoomed out. Demo data retuned to
    show 1-2 turns per day.
    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
2026-07-13 Mockup v1.0: continuous clock donut, future white, tap-to-jump
    Clock dials are now one continuous ring (per-5-min zone segments
    merged by color) instead of 12 separated hour wedges: green/red/orange
    flow into each other, hours past "now" stay as a white dashed arc.
    Tapping a red or orange segment jumps the home graph to that ~3 h
    window and switches to the home tab. Clocks read from a deterministic
    demo day (fixed 20:00 cutoff) with an injected morning-low and
    afternoon-high so all three colors and the jump are demonstrable.
    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
